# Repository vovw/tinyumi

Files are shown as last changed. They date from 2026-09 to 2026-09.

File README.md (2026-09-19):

# tinyumi :3

A hand-worn, 3D-printable UMI-style gripper for experiments with the I2RT YAM
linear gripper. Forked from [Yosub Shin’s YAM-UMI](https://github.com/YosubShin/yam-umi).

**tinyumi adds Quest controller supports, printed rail stops, a RealSense D405
mount, rigid prototype fingertips, and two-plate Bambu print projects.** The
original rack-and-pinion jaws, finger holders and YAM interface remain the basis
of the build.

These additions are **fit prototypes**. CAD and mesh checks are recorded, but
physical fit, strength, full hand/cable clearance and tracking performance are
not yet established. End-to-end data collection is not implemented here. The
D405 has a new camera pose; it does not inherit the original fisheye calibration
or the original camera-to-robot matching claim.

## Print and assemble

1. Choose a [full print project](bambu/full_rebuild/README.md):
   - [D405 version](bambu/full_rebuild/tinyumi_full_rebuild_D405_A1_PETG.3mf).
   - [Original fisheye version](bambu/full_rebuild/tinyumi_full_rebuild_A1_PETG.3mf).
2. Print **one** suitable [left or right Quest support](pos-tracking/quest_mount/handumi_v1/README.md)
   separately if using a controller. It is not included in either full project.
3. Follow the [assembly guide](docs/assembly.md) and [fastener table](docs/fasteners.md).
   Check the actual tip threads before buying or fitting tip screws.
4. Verify free jaw travel, end-stop retention and camera/hand clearance, then
   calibrate the chosen camera and pose source.

The full projects target Bambu A1, 0.4 mm nozzle and PETG. Plate 1 holds the
mechanism with four alternative pinions (install one); plate 2 holds two rigid
prototype tips. Original YAM tips can be used instead of the printed prototypes.
Settings are starting points; inspect supports and slice in Bambu Studio.

## What changed

| Addition | Files and details |
| --- | --- |
| Quest controller support | [Left/right HandUMI-derived supports and revised base](pos-tracking/quest_mount/handumi_v1/README.md) |
| Rail retention | [Four end stops and combined Quest/stop base](hardware/rail_stops/README.md) |
| D405 camera option | [One-piece mount, fit gauge and camera screw limits](hardware/realsense_d405/README.md) |
| Printable fingertips | [I2RT-derived rigid prototypes and print manifests](bambu/full_rebuild/README.md) |
| Assembly documentation | [Build order](docs/assembly.md), [screws and inserts](docs/fasteners.md), [change history](CHANGELOG.md) |

The [original BOM](bom/README.md) lists the baseline rails, bearings, straps and
shop supplies. Add hardware from the fastener table for the chosen options;
upstream prices are historical, not a current tinyumi cost estimate.

## Sources and rebuilding

Original CAD is in `hardware/STEP/` and `hardware/STL/`. Each new hardware folder
includes its generator and validation report. See [rebuilding](docs/rebuilding.md)
for commands and limitations. Legacy CAD and illustration filenames are retained
where they identify an upstream part or are consumed by generators.

The [original design notes](DESIGN.md) preserve the fisheye rationale and upstream
measurements. The [marker-based tracker documentation](pos-tracking/README.md)
remains available; its measurements do not validate the Quest alternative.
The earlier [Quest concept](pos-tracking/quest_mount/README.md) is superseded by
the HandUMI-derived supports.

## License and attribution

Original YAM-UMI design by **Yosub Shin**, under the retained [MIT license](LICENSE).
HandUMI-derived supports are Apache-2.0; I2RT reference meshes and derived tips
include their MIT attribution. See [THIRD_PARTY_NOTICES.md](THIRD_PARTY_NOTICES.md)
and the bundled source licenses. tinyumi is not affiliated with or endorsed by
I2RT, HandUMI, or the original UMI authors.

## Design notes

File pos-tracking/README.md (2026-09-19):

# Position tracking

An alternative [HandUMI controller support adapted for tinyumi](quest_mount/handumi_v1/README.md)
includes left/right CAD, a revised plate and an assembly preview. This is a fit
prototype: real controller fit, hand clearance and tracking need physical checks.

**This is an optional add-on.** The default way to recover wrist pose with
tinyumi is camera SLAM from the wrist fisheye, the same approach the original UMI
used — it needs nothing from this directory and keeps collection portable.

What is here is a **dodecahedral ArUco marker ball** on a stalk, observed by an
external forward-facing camera, for setups that can accommodate a fixed camera.
It measures sub-millimetre on settled holds (numbers below), at the cost of
confining collection to that camera's view. Markers use the **`DICT_4X4_50`**
dictionary.

<p align="center">
  The assembled tinyumi gripper with the dodecahedral ArUco marker ball mounted on its wrist stalk
</p>
<p align="center"><em>The assembled gripper with the dodecahedral tracker on its
stalk, held clear of the hand and of the fisheye camera's view.</em></p>

## Parts

| Part | Size (mm) | Notes |
|---|---|---|
| `dodeca_marker_ball_v2` | 51.05 across | Regular dodecahedron; carries the 15 mm markers |
| `stalk_rod_80mm` | 8 × 8 × 80 | Rod holding the ball clear of the hand |
| `wrist_stalk_adapter_v3` | 44 × 14 × 29 | Mounts the stalk to the wrist |
| `wrist_stalk_arc_adapter` | 44 × 14 × 49.8 | Arc-mount variant of the adapter |
| `arc_extender` | 43.5 × 41.5 × 57 | Extends the arc mount |
| `retainer_radial_tab` | 60.3 × 14 × 75.6 | Retains the ball on the stalk |

A dodecahedron is used so that at least one face is well-conditioned for pose
estimation from any viewing direction, which removes the orientation blind spots
a single planar marker has.

## Markers

`marker_sheet_ball_15mm_FIXED.pdf` — **15 mm markers on 19.5 mm tiles**, applied
to the twelve faces of the ball.

> **Print at 100% scale.** In the print dialog, choose *Actual size* and disable
> *Fit to page*, *Shrink oversized pages*, and any scaling. A sheet printed at
> 97% produces pose estimates that look plausible and are wrong by 3% in range —
> a failure that will not announce itself.

After printing, measure a marker with calipers against 15 mm before cutting
anything out. This takes ten seconds and is the only check that catches a
mis-scaled print.

Apply markers with double-sided tape across the **entire** face, not just the
edges, so they cannot curl or lift. A marker that bows near an edge biases the
corner detection that pose estimation depends on.

### Marker placement is not prescribed

There is deliberately **no face-to-ID mapping to follow**. Apply the twelve
markers to the twelve faces in any arrangement, then recover the layout by
running the assembled ball through a solver that estimates each marker's pose in
the ball's body frame from observations across many viewpoints.

This is worth understanding before you build: the ball's geometry is calibrated,
not assumed. It means print-and-stick tolerances are absorbed by the calibration
rather than becoming permanent error, and it means **your ball's mapping will
differ from anyone else's** — the calibration output is specific to the physical
unit you built and has to travel with it.

<!-- TODO: point at the solver. Right now a reader has the hardware and the
     marker sheet but no way to get from "ball with stickers on it" to a usable
     pose stream. Either link the tool you used, name the off-the-shelf
     equivalent, or write down the procedure and the output format. This is the
     single biggest gap for anyone trying to reproduce the tracking. -->

### Measured performance

All figures below were taken with the ball at roughly 94 cm standoff from the
external camera, **on settled holds**.

**Precision**

| Metric | Result |
|---|---|
| Within-hold | 0.46 mm RMS (median), p90 0.68 mm |
| Revisit repeatability | 0.08–0.17 mm SD per axis (lateral 0.12, depth 0.17) |

**Coverage** — the fraction of frames with enough faces visible to solve a bundle
pose. This is where the choice of external camera shows up:

| Camera | ≥1 face | ≥2 faces | ≥3 faces |
|---|---|---|---|
| Sony (4K 30p, H.264) | 100% | 90.8% | 77.5% |
| Arducam B0591 (1080p, focus locked via v4l2) | 79.6% | 68.3% | 59.1% |

The B0591 numbers were measured before any mount or field-of-view tuning for
that camera. The 15 mm faces give it comfortable pixels at this range, so the
gap to the Sony is a field-of-view and mounting difference rather than a
sensor limit — treat 68% as a floor, not a verdict on cheaper webcams.

#### The camera that ended up winning: Arducam B0587 (4K low-light)

After the table above we moved to the **Arducam B0587** (4K STARVIS2 sensor,
~88° FOV, UVC/MJPEG) and it became the workhorse — it is the camera behind
every number in [`dynamic-accuracy.md`](dynamic-accuracy.md):

| Metric | Result |
|---|---|
| ChArUco intrinsics | 0.744 px RMS at 4K |
| Rigid marker-pair RMS (best pairs) | 0.7 mm |
| Detection vs arm speed | flat to 3 m/s — no measured ceiling |
| Per-frame ≥1-face detection, full teleop session | 99.97% |

**Why it works — the motion-blur unlock.** Fiducial tracking during motion
dies by corner smear, not by frame rate: at 25 fps a marker moving 1 m/s
travels 40 mm between frames, but what kills the *decode* is how far it moves
during the *exposure*. The recipe is a very fast shutter on a sensor that can
afford it:

- **Exposure 0.2 ms** (`exposure_time_absolute=2`, manual mode, gain 0,
  sharpness 0). At 0.2 ms, even 3 m/s of motion smears only 0.6 mm —
  sub-pixel at ~1 m standoff — so the corner detector simply never sees
  blur, and the speed ceiling disappears.
- **A low-light sensor makes that exposure usable.** 0.2 ms under ordinary
  indoor lighting starves a typical webcam sensor; the STARVIS2's
  sensitivity yields clean, zero-gain images at that shutter in a bright
  lab. This pairing — fast shutter *enabled by* low-light silicon — is the
  whole trick, and it is worth selecting cameras for explicitly. (In dim,
  ceiling-light-only conditions the same camera certified at 1 ms +
  gain 20 with equivalent tracking quality.)

Hard-won caveats that travel with this camera class:

1. **Control readback lies.** UVC exposure writes are accepted and read
   back correctly *whether or not the imaging pipeline latched them* — and
   on some modules they only latch after streaming has started. Apply the
   settings mid-stream and verify **behaviourally**: wave a hand in front
   of the lens; at 0.2 ms it must be frozen, not smeared. We lost a full
   session to trusting readback before learning this.
2. **Image brightness is not an exposure probe** on HDR/tone-mapping ISPs —
   some modules normalise brightness toward a target regardless of the real
   exposure. Streaks and blur are the probe; brightness is not.
3. **Some modules' `focus_absolute` is accepted but inert** (the B0587
   focuses by physically rotating the barrel only). Verify focus with a
   live sharpness meter, then mechanically lock the barrel with a witness
   mark — and recalibrate intrinsics after *any* barrel movement.
4. **Flickering LED lighting strobes at sub-millisecond shutters.** Room
   light that looks steady to the eye can beat against a 0.2 ms exposure;
   use DC or high-frequency-driven lighting for the capture volume.

#### Locking focus on the external camera

**Lock the external camera's focus before collecting anything.** The Arducam is
an autofocus module, and autofocus is actively harmful here: refocusing changes
the effective focal length, which shifts the pose solution under a camera the
calibration assumes is fixed. The result is drift that looks like tracking noise
and is not.

There is no hardware switch — set it through V4L2 on Linux. Control names differ
across kernel and driver versions, so list them first:

```
v4l2-ctl -d /dev/video0 --list-ctrls
```

Then disable autofocus and pin a focus value, using whichever names appeared
(`focus_automatic_continuous` on newer uvcvideo, `focus_auto` on older):

```
v4l2-ctl -d /dev/video0 --set-ctrl=focus_automatic_continuous=0
v4l2-ctl -d /dev/video0 --set-ctrl=focus_absolute=<value>
```

Pick the value by focusing on the ball at your working standoff, reading back
`focus_absolute`, then setting it explicitly. These controls reset when the device
is replugged, so reapply them at the start of every session — or with a udev rule
— and re-run the camera calibration if the focus value ever changes.

#### What these numbers do and do not support

1. **Settled holds only** — *resolved 2026-09*: dynamic tracking has since
   been certified on the real arm at full manipulation speed; see
   [`dynamic-accuracy.md`](dynamic-accuracy.md). The 0.46 mm figure remains
   the settled-hold precision, consistent with the 0.7 mm rigid-pair RMS
   measured there.
2. **Relative, not absolute** — *resolved 2026-09*: the 14% scale / 9°
   direction discrepancies were extrinsics error, fixed by a proper
   robot-world hand-eye calibration; absolute robot-frame pose now agrees
   with forward kinematics to 7.7 mm median / 22.7 mm p95, with the
   hand-eye residual (4.8 mm) as the floor. Details and method in
   [`dynamic-accuracy.md`](dynamic-accuracy.md).

<!-- TODO: publish the calibration procedure itself — how the bundle solve is run
     and what it outputs — so someone else can reproduce these numbers rather than
     just read them. -->

## Aperture markers

Gripper aperture is read from ArUco markers on the gripper tips, seen by the
wrist fisheye camera.

`markers/tip_markers_9mm_ID13_14.pdf` — **9 mm markers, IDs 13 and 14**, one per
tip. The 9 mm size is chosen to stay resolvable in the fisheye view, where the
tips sit well off-axis and the effective resolution is much lower than the
sensor's nominal figure suggests.

The same 100% scale rule and full-face taping apply as for the ball markers
above.

Each marker sits **25 mm from the gripper base** — as far from the fisheye camera
as the tip's flat area allows. The camera looks down at an angle, so distance from
it moves the marker toward the centre of the frame and away from the distorted
edge; the limit is mechanical, not optical, since the tip narrows and eventually
offers no flat patch wide enough to seat a marker. See
[assembly](../docs/assembly.md#4-aperture-markers).

An earlier variant detected aperture from the external forward-facing camera
instead, using 12 mm markers on printed tails that carried them behind the jaws.
That approach and its parts live in a separate repository, since they belong to
the external-camera setup rather than to this one.

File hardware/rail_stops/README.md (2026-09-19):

# Rail end stops

Four small printed stops for the two 100 mm MGN9 rails in tinyumi. Each stop
bolts to an end face of the printed plate and catches the outer shoulder of a
carriage. The top stays below the moving jaw adapter.

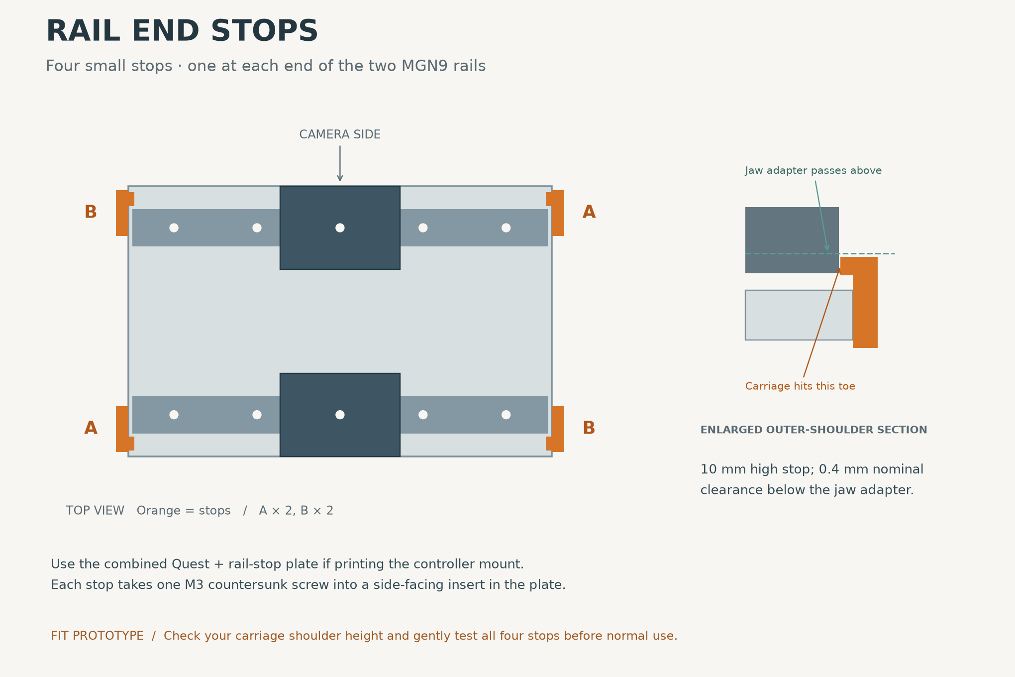
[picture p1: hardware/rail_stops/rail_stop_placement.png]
Placement


## Print these

- **`rail_stops_four_flat.3mf`**: recommended; four separately named objects,
  broad mounting faces flat on the bed, 8 mm gaps and matching A/B diagonals.
  This is a geometry-only 3MF; select your printer and PETG profile in the slicer.
- `rail_stops_four_on_plate.stl`: the same corrected arrangement as one STL.
  This file replaces the earlier upright print layout.
- Individual parts: `rail_stop_A_print_2.stl` and `rail_stop_B_print_2.stl`.
  Print two of each; use A on one diagonal pair of corners, B on the other.
- **`plate_v6_quest_and_rail_stops.stl`**: use this replacement plate for the
  Quest mount plus these stops. It includes both sets of insert holes.
- `plate_v6_with_rail_stops.stl`: alternative plate for the stops alone.

Editable STEP files accompany each part. `build.py` generates the geometry,
placement drawing and checks; `validation.json` records their results.

**The existing plate has no side-facing holes for these stops.** Print the
appropriate revised plate. Both the stock plate and the earlier Quest-only
plate need this revision to accept the stops as drawn. The rails stay standard.

## Hardware and assembly

Per gripper, add four M3 x 5 mm heat-set inserts with nominal 4 mm OD and four
M3 x 8 mm, 90-degree countersunk screws. These are additional to the two screws
and inserts used by the Quest support.

1. Print the stops in PETG, approximately 0.2 mm layers and four walls. The
   individual stop STLs and four-part layout now sit broad-face down on Z=0,
   4.5 mm high, with vertical screw holes and countersinks facing the bed.
   See `rail_stops_print_layout.png`. Print settings are a starting
   point, not experimentally verified settings.
2. Fit the four inserts into the **narrow end faces** of the new plate, with the
   insert axes parallel to the rails. Nominal centres are x=±51, y=±24.5,
   z=3 mm in the plate frame; bores are 4 mm diameter and 5.4 mm deep. Check your
   insert's actual knurl diameter before fitting. There is only 1 mm nominal
   wall above and below each bore, so avoid overheating the pocket.
3. Bolt one stop at each corner using the A/B arrangement shown above. The small
   raised toe points inward along the rail and sits on the outside shoulder of
   its carriage. Seat screws without crushing or twisting the printed stop.
4. Gently slide each carriage toward each stop. It must contact the toe while
   remaining fully on the rail. Check that the carriage cannot lift, bypass or
   rotate the stop. Then sweep the gripper through its intended opening range.

Keep a temporary restraint at the rail ends until all four stops have passed
that check. These are stops for hand-operated travel, not crash bumpers.

## Geometry and checks

The stop face is at x=±49.5 mm, 0.5 mm inboard of the nominal 100 mm rail ends.
The toe spans z=7.8–10.0 mm; the adapter CAD starts at z=10.4 mm, leaving 0.4 mm
nominal vertical clearance. All stop material lies outside |y|=20.5 mm, clear
of the reference finger-holder envelope by about 0.48 mm. These are small
nominal clearances and require checking against the printed assembly.

Nominal MGN9C dimensions from the [HIWIN catalogue](https://www.hiwin.com/wp-content/uploads/HIWIN-Linear-Guideway-Catalog.pdf)
are rail width 9 mm, rail height 6.5 mm, carriage width 20 mm, carriage length
28.9 mm and carriage underside height 2 mm above the mounting surface. With
the rail mounted on the plate's z=6 mm face, the outer carriage shoulder begins
at z=8 mm and meets the toe. Clone carriages can differ: **verify that your
carriage actually has a shoulder in the z=7.8–10.0 mm band.**

For that nominal block, the stop gives approximately ±35.05 mm of carriage-centre
travel, a total 70.1 mm. This is carriage travel, not gripper aperture. The
existing assembly GLB uses a simplified carriage envelope; this contact check
uses the catalogue dimensions rather than treating that envelope as supplier CAD.

Checks run: valid single CAD solids, watertight stop and plate STLs, no stop/plate
or stop/rail intersection, nominal carriage contact before the rail end, and
adapter/finger-holder clearance. Actual clone dimensions, physical full-stroke
operation, screw fit, impact resistance and retention remain untested.

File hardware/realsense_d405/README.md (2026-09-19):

# RealSense D405 replacement mount

A one-piece PETG bracket replacing the original fisheye mount on one tinyumi.
It fits the existing camera insert pair on the underside of plate_v6, including
the combined Quest + rail-stop plate. No new holes in the gripper base are required.

- `d405_mount_print.stl`: oriented printable part; supports required.
- `d405_mount_assembly.step` / `.stl`: part in the base's assembly coordinates.
- `d405_rear_fit_gauge.stl`: small 5 mm-thick test piece for the D405 rear screw pair.
- `d405_on_base.glb` / `d405_mount_preview.png`: schematic camera envelope on the base.
- `D405_ENVELOPE_NOT_FOR_PRINT.step`: nominal body envelope, not supplier CAD.
- Updated full print project: `../../bambu/full_rebuild/tinyumi_full_rebuild_D405_A1_PETG.3mf`.

## Screws and installation

1. Check the rear-hole gauge against the camera before printing the long bracket.
2. Attach the camera to the bracket with **two M3x8 socket-head screws** through
   the 5 mm pad: nominal penetration is 3 mm. The camera's maximum M3 insertion
   is **4 mm**. Measure the printed pad and actual screw protrusion; do not force
   a screw that bottoms out. No heat-set inserts are needed at this joint.
3. Attach the foot under the base's camera-side end with **two M3x8, 90-degree
   countersunk screws**, entering the existing base inserts. The foot is 5 mm
   thick at the screw axis, giving about 3 mm engagement. Base inserts retain
   their existing specification; supplier-specific hole resizing is not applied.
4. Both lenses face the tips. The stereo baseline runs along jaw travel.
   Rear access and both cable sides are open; check the actual Micro-B plug and
   cable bend before tightening. Tie the cable to the arm with slack at the plug.
5. Sweep the jaws and try the hand straps before use. Check camera view across
   the complete aperture range.

## Geometry and print setup

The base pair is at X=±20.285398 mm, Y=29 mm in the existing plate frame.
The camera rear pair is horizontal, 20 mm apart, on a 42x16x5 mm back pad.
Most of the camera back and all side faces remain exposed.

Camera rear centre: (0,100,0) mm; view direction (0,-0.707107,0.707107).
The 45-degree angle aims toward the nominal fingertip region near (0,0,100).
This is a chosen design pose, not a preserved fisheye extrinsic or measured
optical centre. The 42x42x23 mm body envelope does not include the side protrusion
or a cable plug. Neither side is enclosed by the bracket.

Print STL bounds: 54x86x30.657 mm. Full project uses A1/0.4 mm, PETG, 0.2 mm
layers, four walls, 30% gyroid, normal snug supports. Remove supports from screw
holes and both mounting faces before assembly. Physical fit/strength untested.

CAD checks: single valid solid, watertight mesh, zero nominal base/body overlap,
and a 33.9 mm Y gap from camera envelope to a conservative moving-jaw band.
Hand/strap/cable geometry is not included. These are geometric checks, not load
or full-motion certification.

## Camera integration

This is a mechanical change only. The D405 is a close-range stereo camera, not
the original fisheye. Capture integration, camera calibration, marker visibility,
and camera-to-gripper extrinsics need checking with the D405 before collecting
usable data. Existing fisheye calibration must not be reused.

## Dimensional source

RealSense D400 Series Datasheet, October 2025, Figure 10-13, printed page 146:
https://realsenseai.com/wp-content/uploads/2025/09/Intel-RealSense-D400-Series-Datasheet-October-2025.pdf
Rear M3 pair: 20 mm pitch; maximum insertion 4 mm; body 42x42x23 mm.
Original bracket design in this folder; camera envelope is schematic.

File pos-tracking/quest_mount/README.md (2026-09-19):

# Quest Touch Plus mount — concept v0

**Superseded:** use the [actual HandUMI support adaptation](handumi_v1/README.md).
The tall-cradle files below are retained as an earlier design study.

Design study for tinyumi with Quest 3 / 3S and Touch Plus controllers. This is a
prototype concept, not a fit-verified production part. Controller contact shape,
tracking visibility, fastener access and full hand/jaw clearance need physical
verification. No Quest tracking integration has been installed or measured here.

## Deliverables

- `quest_mount_concept.png`: annotated CAD concept view.
- `quest_mount_CONCEPT.step`: editable solid for fitting in CAD.
- `quest_mount_CONCEPT.stl`: prototype mesh; not a release-ready print.
- `build_concept.py`: parametric source and reproducible rendering/export.
- `concept_validation.json`: geometric checks and explicitly unverified items.
- `controller_ENVELOPE_NOT_FOR_FIT.stl`: simplified visual placeholder only.

The initial flange pitch is 40.57 mm, taken from the circular edge centers at
x = ±20.285, y = 29 mm in `hardware/STEP/plate_v6.step`. These are 4 mm diameter
features; the concept uses M3 clearance holes for an insert-based attachment.
This is an interface candidate, not proof of available mounting real estate:
the camera already uses this region. Resolve the installed camera fastener
stack, access, actual thread and full surrounding clearances before fitting.
The exported part is in its own local frame, not a verified assembly transform.

Nominal concept dimensions: 56 x 24 x 6 mm flange, 62 mm controller-axis offset,
4 mm saddle wall, 48 mm saddle height and two 10 mm retention bands. The
38 x 34 mm inner ellipse is a provisional contact envelope, not a measured
Touch Plus cross-section. It must be refitted before tightening onto a controller.
The displayed bands are illustrative purchased straps; the controller envelope
and bands are excluded from the printable mount STL.

For a first fit coupon, section just the saddle in CAD and check it against the
controller before printing the bridge. PETG is a reasonable prototype material;
use multiple walls and orient the bridge to avoid a weak layer-peel load path.
Print settings and strength are not validated. Measure the final fastener stack
before choosing screw lengths, and add a loose controller safety tether.

## Recommendation

Prototype Quest as an alternative pose source. It can remove the external pose
camera, marker-ball calibration and ball stalk from portable collection. Keep
the YAM wrist camera and aperture markers: a controller measures its own pose,
not the opening of the mechanical jaws. The wrist camera USB cable remains.

At the time of this concept study, the repo reported 0.46 mm RMS within settled holds, not moving TCP
accuracy, and unresolved 14% scale / 9 degree direction discrepancies against
robot FK. The subsequently merged [upstream dynamic-accuracy report](../dynamic-accuracy.md)
updates those baseline limitations; it does not validate this Quest concept.
Quest is not a demonstrated accuracy upgrade. Its benefit is likely
collection convenience; dynamic accuracy, occlusion, drift and reacquisition
need an apples-to-apples comparison. The tracker solver itself was not found in
this checkout, so this comparison uses its hardware and published measurements.

## Mechanical layout

Borrow HandUMI's controller-over-the-hand arrangement, while keeping this
project's YAM camera-to-jaw geometry. Use a rigid load path:

    stationary gripper plate -> short braced bridge -> controller cradle

Do not use the moving finger holders or a skin-mounted wrist strap as the pose
reference. Do not put a controller on the existing 80 mm, 8 x 8 mm marker stalk
without a separate stiffness/load assessment. A wrist strap can be a loose
safety tether, but must not change the controller-to-gripper transform.

The proposed concept has a two-screw mounting flange, a short boxed/gusseted
bridge and an open cradle. A hard locating surface and two separated retention
bands resist sliding and rotation. Thin replaceable pads protect the controller;
soft padding must not become the structural reference. Final pads and locating
surfaces must match a measured controller section. The opening is deliberately
parametric rather than claiming a scan-derived Touch Plus fit.

Keep the controller face, upper perimeter, lower tracking region, buttons and
trigger clear. The controller bottom remains open. Verify IR visibility with
the real controller and headset, including both hands crossing, palm-down
grasps, reaching into shelves and looking away. Mounting the controller on a
gripper differs from its normal held-in-hand use and must be validated as such.

Use the shortest bridge that clears the actual hand and wrist-camera image.
Start with a fixed mount; change its geometry between trials rather than using
an unlocked ball joint. Every change to controller seating or mount geometry
requires a new controller-to-TCP calibration. Left and right controller contact
surfaces should be fitted separately rather than assuming perfect mirroring.

## Pose integration

[HandUMI Quest App](https://github.com/murobotics-ai/handumi-quest-app) already
streams controller and headset telemetry. Its
[protocol](https://github.com/murobotics-ai/handumi-quest-app/blob/main/protocol.md)
documents newline-delimited JSON over TCP port 65432, tracked/valid flags,
runtime timestamps and UDP clock synchronization on port 42000. Its presence
does not by itself make the tinyumi recording pipeline complete.

There is also a local `vr-teleop-kit` project with a Quest WebXR pose transport.
Its clutching, gain scaling and IK outputs are for teleoperation. For physical
demonstration recording, take raw metric poses before those modifications.
Record the exact pose reference used (grip versus aim, runtime convention),
source time, reception time, tracking state and coordinate-frame convention.

With T_A_B mapping coordinates from B into A:

    T_world_tcp(t) = T_world_controller(t) * T_controller_tcp

Calibrate both translation and rotation of T_controller_tcp with a rigid
fixture and multiple orientations. Pivot calibration alone finds an offset;
it does not determine the complete orientation alignment. If deployment needs
the robot base frame, additionally calibrate T_robot_world. Verify handedness,
quaternion order, metres and axis conversion with known translations/rotations.
Do not multiply by the HMD pose again if the app already sends world poses.

Synchronize Quest source time with wrist video and aperture timestamps. TCP
arrival time is not acquisition time. Record/reject stale and invalid poses;
never silently carry a frozen pose through a tracking outage. Split or reject
episodes after recentering/relocalization discontinuities until the world frame
is re-established. Quest still uses internal tracking/SLAM; it removes the need
to implement an offline wrist-camera pose solver, not every calibration step.

## Before choosing it over the ball

1. Fit the cradle to the actual Touch Plus controller. Confirm no button preload,
   bottom obstruction or controller slip, and full aperture/hand/camera clearance.
2. Attach both trackers temporarily to the same rigid body, keeping both visible.
   Measure their fixed extrinsic and time offset; compare at the same TCP.
3. Record static holds, repeated fixture returns, measured straight motions,
   fast wrist rotations, occlusions and ten-minute trajectories. Include removal
   and reinsertion of the controller to measure mount repeatability.
4. Compare valid-frame fraction, outage duration, recovery jumps, lag, relative
   trajectory agreement and start/end drift. Use an independent measured fixture
   or calibrated reference for absolute error: disagreement alone cannot tell
   which tracker is right, especially with the existing unresolved FK comparison.
5. Choose acceptance limits from the intended manipulation task before comparing.
   Keep the ball as a debug/reference option until Quest passes those limits.

Mount stiffness matters: 1 degree of angular motion over a 150 mm lever arm
produces about 2.6 mm of apparent TCP displacement. Those are illustrative
values, not measured dimensions or errors for this build.

## Sources and scope

- [HandUMI hardware](https://github.com/murobotics-ai/handumi-hw): controller
  supports and wrist-mounted VR tracking. Local reference inspected at ef0c784.
  Arrangement inspiration only; no upstream CAD is copied into this concept.
- [HandUMI software](https://github.com/murobotics-ai/handumi-sw): Quest support
  and physical controller-to-TCP calibration metadata.
- [Current tracker](../README.md) and [tinyumi](../../README.md): existing
  mechanism, marker geometry, measured settled-hold statistics and limitations.

Upstream pages inspected 2026-09-12. This work adds a design study alongside the
existing tracker; it does not claim the Quest replacement has been validated.

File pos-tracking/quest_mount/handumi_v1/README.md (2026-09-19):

# HandUMI controller support adapted for tinyumi

This replaces the earlier tall-cradle concept. The controller rings come from
HandUMI's actual left and right STEP files. Their mounting forks are trimmed
and replaced with short angled tabs. One support attaches with two screws.

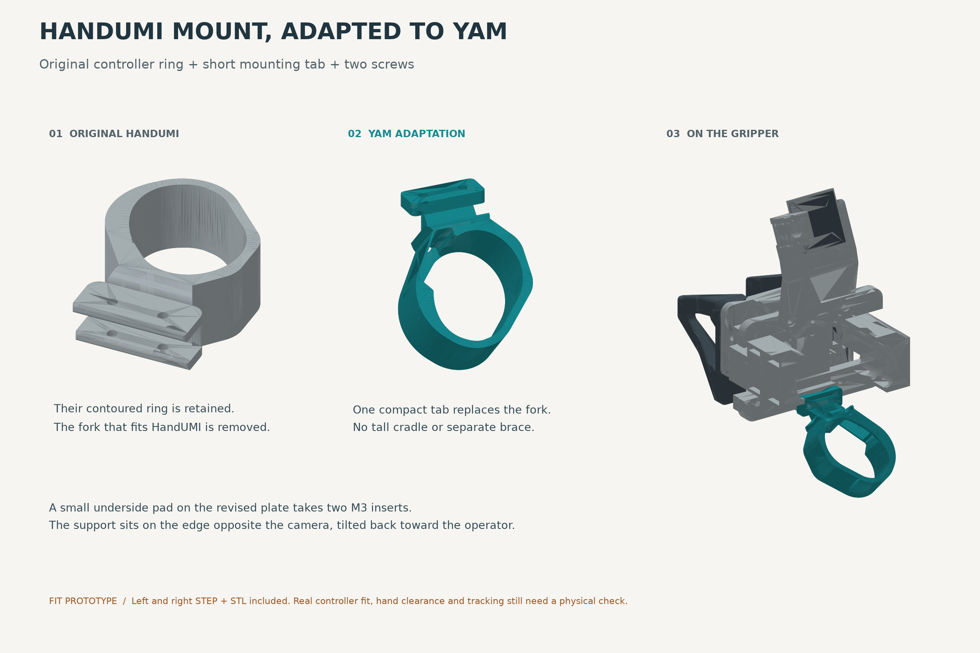
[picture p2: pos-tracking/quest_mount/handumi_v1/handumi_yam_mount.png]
Adaptation


## Files

- `handumi_yam_right_support.step` / `.stl`: adapted right support.
- `handumi_yam_left_support.step` / `.stl`: adapted left support.
- `plate_v6_handumi_mount.step` / `.stl`: revised stationary plate, used with
  either support. **This support needs the revised plate; it does not bolt onto
  an unmodified plate_v6.**
  If your rails lack end stops, use the
  [combined Quest + rail-stop plate](../../../hardware/rail_stops/README.md)
  instead; it also accepts the four printed rail stops.
- `yam_with_handumi_mount.glb`: assembly preview, in metres. Other assembly
  components come from the existing illustration and include simplified parts.
- `build.py`: repeatable CAD modification, export, rendering and checks.
- `validation.json`: geometric results and remaining physical checks.
- `source/`: pinned, unmodified upstream supports and Apache-2.0 licence.

## What changed

The original contoured rings and their existing retention features are retained.
The HandUMI-specific fork attachment is replaced by a small two-hole tab and
short neck. The ring is tilted 45 degrees back toward the operator, on the edge
opposite the camera. There is no tall cradle, additional cage or separate brace.
The left and right sources are distinct parts, not assumed mirror copies.

The revised plate adds a 30 x 12 x 4 mm pad on its underside, centred at
(0, -26.5) mm in the original plate frame. Two insert bores are centred at
(±8, -28) mm: 16 mm pitch, nominal 4 mm bore diameter and 5.4 mm depth from the
pad underside. Material above z=2 mm is unchanged, retaining the original rail,
pinion and camera geometry. Existing rail or camera screws are not repurposed.

The support tab is 5 mm thick with 3.4 mm clearance holes and 6.4 mm countersink
mouths. Start with two M3 x 5 mm heat-set inserts, OD 4 mm, and two M3 x 10 mm
90-degree countersunk screws. Verify the actual insert fit and screw engagement
before assembly; insert knurl specifications vary. The tab meets the underside
pad at z=-4 mm. The source CAD units and all exported STEP/STL units are mm.

## Fit prototype, not a tested release

The support and plate are valid single solids with watertight meshes. The build
checks support/plate interference and conservative bounding-box clearance against
the existing assembly. Moving-part X bounds are expanded over the plate width
to check lateral jaw travel; this is a geometry screening check, not a dynamic
simulation or a measured assembly fit.

**The upstream files do not establish a physically verified Touch Plus fit for
your particular controllers.** Their original controller contact geometry is
preserved rather than replaced with the guessed ellipse from the first concept.
Try the appropriate ring on your Quest 3 / 3S controller before printing the
replacement plate. Do not force it on or sand away a locating surface without
checking tracking and repeatability again.

Check the real controller body, buttons, tracking surfaces, hand, wrist, straps
and USB cable in the mounted position. Those are not modelled in the assembly
clearance check. In particular, the controller body can occupy space beyond the
printed ring. Use a loose safety tether during trials and confirm the controller
cannot slide or rotate in the ring. Tracking accuracy and print strength have
not been tested. Keep the original camera and aperture-marker setup.

For prototype printing, PETG matches the existing build. Orient the support in
the slicer with the neck load path in mind and inspect required supports; the
STLs retain assembly coordinates, not a prescribed print orientation. Check
insert fit on a small coupon first.

## Provenance and licence

Modified from [murobotics-ai/handumi-hw](https://github.com/murobotics-ai/handumi-hw)
at commit `fc7462ad1ed58c0c8538f6c7dbb732211d088ca8`:

- `hardware/STEP/right_handumi/right_controller_support.step`
- `hardware/STEP/left_handumi/left_controller_support.step`

The upstream parts and derived supports are distributed under Apache-2.0; see
[source/LICENSE](source/LICENSE). Modifications made 2026-09-12: removed the
original fork mounting ends, transformed ring placement, added YAM mounting
tabs, and created the associated plate interface. Original source STEP files
are retained unmodified, with SHA-256 hashes in `validation.json`.

The plate derives from this repository's `hardware/STEP/plate_v6.step`. Assembly
illustrations also use the repository's existing I2RT-derived tip meshes; see
the root `THIRD_PARTY_NOTICES.md` for their provenance.

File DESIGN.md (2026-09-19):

# Original YAM-UMI design notes

Upstream design rationale and measurements through `9d202bc`. These describe the original camera and marker-tracker builds, not validation of tinyumi’s Quest, D405, rail-stop or printed-tip additions. See the [tinyumi README](README.md) for the current build.

# YAM-UMI

An open-source, hand-worn [UMI](https://umi-gripper.github.io/)-style data
collection device for the **[I2RT YAM](https://i2rt.com/products/yam-6-dof-arm)
arm's linear gripper**.

YAM-UMI is deliberately built for one arm.
It mirrors the YAM linear gripper's jaw geometry, reuses the YAM wrist camera
mount, and reproduces the gripper's own rail-and-pinion mechanism, so **the
camera pose relative to the gripper tips, and the way those tips move, are the
same during data collection as on the deployed robot**. Aperture is recovered
from ArUco fiducials rather than a servo encoder, so there is no motor to
backdrive and no loaded plastic linkage to fail.

<p align="center">
  The YAM arm's linear gripper beside the YAM-UMI handheld device, showing matched jaw geometry and the same wrist camera mount
</p>
<p align="center"><em>Left: the YAM arm's gripper. Right: YAM-UMI. Same jaw geometry,
same camera mount, same tips — so the wrist camera sees the same thing in both.</em></p>

<p align="center">
  Operator performing a pick-and-place with the YAM-UMI gripper, dodecahedral tracker visible above the wrist
</p>
<p align="center"><em>Pick-and-place demonstration, with the dodecahedral wrist tracker
attached. Full quality: <a href="media/demo-pick-place.mp4">demo-pick-place.mp4</a>.</em></p>

> **Status: hardware released, pipeline in progress.** The mechanical design is
> printed and assembled, and the optional wrist tracker is characterised for
> settled holds (0.46 mm RMS). End-to-end data collection and policy training with
> this device have not been run yet, and the parity claims below are by
> construction rather than measured — see
> [Status and limitations](#status-and-limitations).

## Why another UMI variant

The point of a UMI-style rig is to collect demonstrations without a robot in the
loop, then train a policy that consumes wrist-camera images. That only works if
what the camera sees at collection time resembles what it sees at deployment
time.

That principle is UMI's own, not this project's. The
[UMI paper](https://arxiv.org/abs/2402.10329) states it directly — *"When
deploying UMI on a robot, we place GoPro cameras with the same location with
respect to the same 3D-printed fingers as on the hand-held gripper"* — and reports
wrist-camera video that is "almost indistinguishable" between demonstration and
deployment.

What differs between designs is the **direction** in which the match is made. UMI
adapts the robot to the interface: mount UMI's fingers and a GoPro on any arm with
a parallel jaw stroke over 85 mm, and the match follows. YAM-UMI adapts the
interface to the robot: the arm keeps its stock gripper tips and stock camera
mount, and the handheld device changes to match. That direction suits a fleet
already standardized on one arm, or a deployment configuration you would rather
not modify — at the cost of fitting nothing else.

This design began as an attempt to use
[HandUMI](https://github.com/murobotics-ai/handumi-hw) on a YAM. HandUMI is one
of the few open hand-worn UMI designs whose linkage keeps the two jaws
**synchronized**, moving together the way a parallel gripper does rather than
independently following the operator's two fingers. For anyone targeting a linear
gripper that property is the hard part, and it made HandUMI the natural starting
point here. Two things kept it from working on a YAM.

### 1. The camera extrinsic could not be matched

HandUMI takes a third position: rather than adapting either side, it keeps one
shared body across arms and swaps only the gripper tips, leaving the rest to
software retargeting. That is what lets a single rig serve an AgileX Piper, an ARX
X5, a Trossen WidowX and others — but it means the wrist camera sits where the
shared body allows, and its mount does not readily adjust to reproduce the YAM
camera's angle relative to the gripper tips. The resulting viewpoint shift is a
domain gap the policy has to absorb.

YAM-UMI instead reuses the YAM gripper's own fisheye camera mount on a body that
reproduces the YAM jaw geometry, so the camera-to-tip transform is matched by
construction rather than corrected in software. Because the device also accepts
the **actual gripper tips that ship with the YAM arm**, the jaws occlude the same
part of the frame, the aperture-to-pixel mapping is the same, and the contact
patch on the object is the same.

The cost is generality: this rig targets the YAM linear gripper and nothing else.
That is a deliberate trade, not an oversight.

### 2. The servo and the lever linkage

HandUMI measures aperture with a Feetech servo encoder, which gives a clean
per-frame width signal. The operator pays for it by backdriving the servo through
its gear train on every pinch, adding friction to the one motion the device
exists to record faithfully.

The linkage was the more immediate problem. In hand, its printed lever parts
popped out of the mechanism under normal use — the load path runs through
printed plastic links, and that is where it failed.

YAM-UMI carries the motion on two MGN9 linear rails instead, with a single pinion
between two racks — one rack per jaw — to keep the jaws synchronized.

**This is the mechanism the YAM gripper itself uses.** Two MGN9 rails, two racks,
and a pinion is not an arbitrary alternative to the crank linkage; it is what is
inside the robot's own linear gripper. So the parity here is not only optical and
geometric but *kinematic*: the jaws travel the way the robot's jaws travel, the
aperture is symmetric about the same centerline, and the relationship between the
operator's pinch and the resulting width is the one the robot can actually
execute. There is no mechanism-level retargeting between collection and
deployment, because there is no mechanism difference to retarget.

Aperture is read from ArUco markers, the approach the original UMI used.
Consequences:

- **No backdrive friction.** The pinch is governed by the rails and the
  rack-and-pinion coupling only.
- **No servo, controller, or power supply** in the bill of materials, and no
  cable routing for them.
- **No loaded lever linkage.** The printed parts are brackets and mounts, not
  structural links carrying the pinch load.

<p align="center">
  View from the gripper tip side: a central pinion meshing with a rack on each jaw, keeping the two jaws synchronized
</p>
<p align="center"><em>Viewed from the tip side: one pinion between two racks, one rack
per jaw, riding two MGN9 rails — the same arrangement as inside the YAM arm's own
linear gripper. A single-handed pinch drives both jaws symmetrically, with no
servo in the loop and no linkage carrying the load.</em></p>

## What it records

| Signal | Source |
|---|---|
| Wrist pose, SE(3) | Camera SLAM from the wrist fisheye — the original UMI approach, and the default here. Optionally, a dodecahedral ArUco marker ball observed by an external camera |
| Gripper aperture | 9 mm ArUco markers on the gripper tips, seen by the wrist fisheye camera |
| Wrist-view video | Fisheye USB camera on the YAM camera mount |

SLAM is the default because it keeps collection portable, which is the whole
point of a UMI-style rig. Nothing in this repository is required for it — the
wrist camera and mount are all it needs.

### Optional: dodecahedral wrist tracker

If your setup can accommodate a fixed external camera, this repository also
includes a dodecahedral marker ball and the mounts that attach it to the gripper.
It buys precision at the cost of confining collection to the camera's view.

Measured with the ball at roughly 94 cm standoff, **on settled holds**:

| Metric | Result |
|---|---|
| Within-hold precision | 0.46 mm RMS (median), p90 0.68 mm |
| Revisit repeatability | 0.08–0.17 mm SD per axis (lateral 0.12, depth 0.17) |

Coverage — the fraction of frames with enough faces visible to solve a bundle
pose — depends strongly on the external camera:

| Camera | ≥1 face | ≥2 faces | ≥3 faces |
|---|---|---|---|
| Sony (4K 30p, H.264) | 100% | 90.8% | 77.5% |
| Arducam B0591 (1080p, focus locked via v4l2) | 79.6% | 68.3% | 59.1% |

**Update (2026-09):** both of the original caveats — settled-holds-only, and
absolute pose unresolved — have since been resolved by measuring this same
ball design on the real YAM arm against its joint encoders. During full-speed
teleoperated manipulation (30 episodes, ~23k frames), fused-ball pose agrees
with the robot's forward kinematics to **7.7 mm median / 22.7 mm p95 / 1.7°**
at a tool point 13 cm from the ball, with pose solved in 98.5% of frames;
the error budget is dominated by the hand-eye calibration (4.8 mm residual),
not the camera. The earlier 14%/9° discrepancies were extrinsics error, fixed
by a proper `calibrateRobotWorldHandEye` solve harvested from ordinary
episodes. Full numbers, method, and known failure modes:
[`pos-tracking/dynamic-accuracy.md`](pos-tracking/dynamic-accuracy.md).

The Arducam coverage was measured before any mount or field-of-view tuning for that
camera, so it is a floor rather than a verdict on cheaper webcams.

See [`pos-tracking/README.md`](pos-tracking/README.md) for the build and
calibration procedure.

A VR-controller mount is not provided but would be straightforward to add —
contributions welcome.

## Parts

### Gripper body — [`hardware/`](hardware/)

Printed parts are provided as STEP and STL. The STEP files are the source of
truth; the STLs were tessellated from them at 0.05 mm chordal tolerance and are
watertight, so re-export from STEP if you want a different resolution.

| Part | Size (mm) | Role |
|---|---|---|
| `plate_v6` | 102 × 65 × 10.4 | Main plate; carries both linear rails, the camera arm, and the pinion axle |
| `adapter_v10` | 50 × 25.9 × 10.6 | Carriage-to-jaw adapter; presents the YAM gripper tip interface |
| `pinion_z18_deep_v0`–`v3` | ⌀20.0–19.7 × 10.6 | Module 1, z=18 spur pinion coupling the two jaw racks for symmetric motion, as in the YAM gripper. Four fit variants — see [Printing](#printing) |
| `handle_v13` | 32 × 17 × 55 | Operator handle |
| `L_bracket_v3` | — | Camera arm bracket |
| `YAM_linear_gripper_fisheye_camera_mount` | — | Fisheye camera mount, matching the YAM wrist camera pose |

<!-- TODO: confirm the Role column. The pinion/rack coupling is confirmed by the
     tip-side photo, but the plate, adapter, handle and bracket roles are still
     inferred from geometry rather than from your notes. -->

**Gripper tips are not printed.** Use the "Linear 4310" tips that ship with the
YAM arm — that is what makes the contact geometry identical to deployment. If you
do not have spares, I2RT sells them as
[Gripper Tips (for Linear-Gear Style Gripper)](https://i2rt.com/products/gripper-tips-for-linear-gear-style-gripper)
($69), though they are frequently out of stock.

### Position tracking — [`pos-tracking/`](pos-tracking/)

See [`pos-tracking/README.md`](pos-tracking/README.md) for marker specifications
and printing instructions.

- `wrist_dodecahedron_marker/` — the dodecahedral marker ball (51 mm across),
  its stalk, wrist adapter, arc adapter, extender, and retainer, plus the 15 mm
  marker sheet.
- `markers/` — the 9 mm tip-marker sheet (IDs 13, 14) used for aperture sensing
  from the wrist fisheye camera.

Marker placement on the ball is not prescribed: stick the twelve markers on in
any arrangement and recover the face-to-ID mapping by calibration. That absorbs
print-and-stick tolerances instead of baking them in as permanent error, but it
also means each ball's calibration is specific to the unit it was measured on.

## Build

- [Bill of materials](bom/README.md) — ~$79 per gripper in parts, plus shop supplies (filament, fastener kits, tape) if you are starting from nothing.
- [Assembly](docs/assembly.md) — build order and fastener placement.

### Printing

Everything was printed in **PETG** on a Bambu Lab X2D with the stock PETG profile
and *Support for PLA/PETG* enabled. No part needed tuning beyond support
settings. PLA should work too — nothing here runs warm and it is an indoor,
hand-held device — PETG is simply what these were printed in.

**The pinion comes in four variants.** `pinion_z18_deep_v0`–`v3` are the same
18-tooth, module-1 pinion at descending outside diameter — 20.0, 19.9, 19.8 and
19.7 mm — a 0.1 mm clearance ladder against the racks. **Print all four on one
plate and pick the one that runs smoothest** in your assembly. Printer, filament
and insert alignment all shift the effective fit, so the right variant is
empirical rather than predictable; `v3` was the best fit in the reference build,
which is why the rest of the docs name it.

## Status and limitations

- **No end-to-end result yet.** The device has not been used to collect a dataset
  and train a policy. The camera-extrinsic parity claim is by construction and
  has not been validated against recorded imagery.
- **Wrist tracker: settled-hold precision 0.46 mm RMS at ~94 cm; dynamic
  tracking and absolute robot-frame pose are now certified** (7.7 mm median
  agreement with the arm's forward kinematics across full-speed
  manipulation) — see
  [`pos-tracking/dynamic-accuracy.md`](pos-tracking/dynamic-accuracy.md).
- **The tracker's calibration procedure is not published**, so the numbers above
  can be read but not yet reproduced.
- **Aperture accuracy is unmeasured.** A comparison of fiducial-derived width
  against the YAM encoder, or against calipers over a swept aperture, would be
  the most valuable single addition to this repo.
- **Fiducial occlusion** is an inherent failure mode; there is no fallback width
  estimate when markers are lost.
- **Single-arm scope.** No support for other grippers is planned.

## Related work

- **[UMI](https://umi-gripper.github.io/)** (Chi et al.,
  [arXiv:2402.10329](https://arxiv.org/abs/2402.10329)) — the original handheld
  gripper, the source of both the fiducial-based aperture sensing this design
  returns to and the principle of minimizing the observation embodiment gap.
  UMI achieves that match by mounting its own fingers and camera on the robot;
  YAM-UMI reverses the direction.
- **[HandUMI](https://github.com/murobotics-ai/handumi-hw)** (Murobotics) — the
  direct starting point for this work, and one of the few open hand-worn UMI
  designs with a synchronized parallel-jaw mechanism. YAM-UMI takes the
  glove-style form factor and the hook-and-loop finger retention from it, and
  diverges on camera placement, jaw mechanism, and aperture sensing for the
  reasons above. If you want a robot-agnostic rig rather than a YAM-specific one,
  or a direct encoder reading of aperture, HandUMI is the better fit. No HandUMI
  CAD is used here.
- **[Generalist](https://generalistai.com/)** — the wearable data-collection
  approach HandUMI credits as its own motivation.

### The robot this targets

- **[YAM 6-DOF arm](https://i2rt.com/products/yam-6-dof-arm)** (I2RT Robotics) —
  the arm YAM-UMI is built for. 6 DOF, 2 kg payload, 95 mm gripper throw.
- **[YAM documentation](https://doc.i2rt.com/products/yam)** — specifications and
  setup for the arm and its linear gripper.
- **[`i2rt-robotics/i2rt`](https://github.com/i2rt-robotics/i2rt)** — the Python
  client library, URDF, and robot meshes. The meshes there are what this design's
  gripper geometry and camera mount are dimensioned from; see
  [THIRD_PARTY_NOTICES.md](THIRD_PARTY_NOTICES.md).

## License and attribution

This project is released under the [MIT License](LICENSE).

Geometry in this repository is dimensioned from mesh files published by I2RT
Robotics under the MIT License. See
[THIRD_PARTY_NOTICES.md](THIRD_PARTY_NOTICES.md) for the full attribution.

**This project is not affiliated with, endorsed by, or sponsored by I2RT
Robotics.** "YAM" is used only to identify the robot arm this hardware is
designed for.

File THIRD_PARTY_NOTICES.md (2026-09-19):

# Third-Party Notices

This project incorporates or derives from third-party material. Each item below
lists what was used and the license it was used under.

## YAM-UMI — original gripper design

tinyumi is a derivative of [YosubShin/yam-umi](https://github.com/YosubShin/yam-umi),
started from commit `2862fe2` and merged through `9d202bc`. The original MIT license and Yosub Shin copyright
notice are retained in [LICENSE](LICENSE). See [CHANGELOG.md](CHANGELOG.md)
for this fork’s additions. Historical design notes and measurements are
preserved in [DESIGN.md](DESIGN.md).

## I2RT — reference meshes and prototype fingertips

`hardware/reference/i2rt_linear_4310/` includes pinned upstream tip meshes,
model XML and MIT license. [source.json](hardware/reference/i2rt_linear_4310/source.json)
records the source commit, paths and hashes. The print prototypes in
`bambu/full_rebuild/tip_*_prototype.stl` trim those meshes to remove the stock
rack; assembly illustrations also derive from these meshes. This is an
additional use beyond the original camera interface described below.

## HandUMI — optional controller supports

`pos-tracking/quest_mount/handumi_v1/` contains original and modified controller
support CAD from [murobotics-ai/handumi-hw](https://github.com/murobotics-ai/handumi-hw),
commit `fc7462ad1ed58c0c8538f6c7dbb732211d088ca8`, under Apache-2.0.
The upstream licence is included in that folder's `source/LICENSE`.
The modified supports retain the controller rings and replace the mounting ends
to attach to tinyumi. See the folder README for source paths and modification
details. These optional supports are an exception to the original-work statement
about `pos-tracking/` below.

## I2RT Robotics — YAM robot models and CAD

This design is dimensioned from three sets of files published by I2RT Robotics
for YAM owners:

- the **YAM URDFs**,
- the **camera mount CAD** for the linear-gear gripper, and
- the **gripper cable retainer**.

Together these are what make the gripper geometry and the wrist camera pose match
the deployed robot.

**Scope of what is derived.** I2RT's plate CAD is supplied as a single merged
mesh, so it provides overall form but no separable components. In the original YAM-UMI release, the gripper mechanism was drawn
from scratch — `plate_v6`, `adapter_v10`, `L_bracket_v3`, `handle_v13`, the pinion
variants, and all of `pos-tracking/` are original work, dimensioned either
independently or by measuring the physical robot. The derived content is the
mounting geometry needed to make the camera pose and jaw interface match, not the
mechanism.

**Source.** These were taken from the CAD folder I2RT distributes to customers,
linked from the [YAM product page](https://i2rt.com/products/yam-6-dof-arm) and
hosted on
[Google Drive](https://drive.google.com/drive/folders/17en5gl898ILuapsgUwBkjy4y5SOWQhB2).
That folder carries no stated licence or terms of use.

**Licence status.** I2RT publishes the same designs, in mesh form, in their
open-source [`i2rt-robotics/i2rt`](https://github.com/i2rt-robotics/i2rt)
repository under the MIT Licence — including
`i2rt/robot_models/arm/yam/v1/` (URDFs and meshes),
`i2rt/robot_models/gripper/linear_4310/assets/d405/camera_bracket_for_D405_linear_4310_.stl`
and `.../Cable_holder.stl`. That MIT grant covers the files in that repository. It
is strong evidence that I2RT intends these designs to be openly used, but it is
not itself a licence for the separately distributed CAD folder, which is where the
geometry used here came from.

The MIT Licence text as published in that repository:

```
MIT License

Copyright (c) I2RT Robotics

Permission is hereby granted, free of charge, to any person obtaining a copy
of this software and associated documentation files (the "Software"), to deal
in the Software without restriction, including without limitation the rights
to use, copy, modify, merge, publish, distribute, sublicense, and/or sell
copies of the Software, and to permit persons to whom the Software is
furnished to do so, subject to the following conditions:

The above copyright notice and this permission notice shall be included in all
copies or substantial portions of the Software.

THE SOFTWARE IS PROVIDED "AS IS", WITHOUT WARRANTY OF ANY KIND, EXPRESS OR
IMPLIED, INCLUDING BUT NOT LIMITED TO THE WARRANTIES OF MERCHANTABILITY,
FITNESS FOR A PARTICULAR PURPOSE AND NONINFRINGEMENT. IN NO EVENT SHALL THE
AUTHORS OR COPYRIGHT HOLDERS BE LIABLE FOR ANY CLAIM, DAMAGES OR OTHER
LIABILITY, WHETHER IN AN ACTION OF CONTRACT, TORT OR OTHERWISE, ARISING FROM,
OUT OF OR IN CONNECTION WITH THE SOFTWARE OR THE USE OR OTHER DEALINGS IN THE
SOFTWARE.
```

I2RT Robotics has not reviewed or endorsed this project. See the non-affiliation
notice in the [README](README.md#license-and-attribution).

## HandUMI (Murobotics)

The original YAM-UMI gripper mechanism did not use HandUMI CAD. The optional
controller supports added in this fork do, as documented above. HandUMI was
the direct starting point for the original work
and is credited as prior art. The design ideas adopted here are the hand-worn,
glove-style form factor, retaining the operator's fingers with hook-and-loop
straps, and keeping the two jaws mechanically synchronized — implemented
independently with a rack-and-pinion on linear rails rather than HandUMI's crank
linkage. HandUMI is licensed under Apache License 2.0.

## Universal Manipulation Interface (UMI)

No CAD from UMI is used here. UMI (Chi et al.) is the origin of the overall
approach, including fiducial-based gripper-aperture sensing, which this design
returns to. See <https://umi-gripper.github.io/>.

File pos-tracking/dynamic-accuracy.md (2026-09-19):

# Dynamic tracking accuracy — dodecahedral ball vs robot ground truth

*Added 2026-09-15. These measurements were made with the same dodecahedral
marker ball and detection stack as this repository, mounted on the real
YAM arm's gripper (not the handheld device), because the robot's joint
encoders provide an independent ground truth that a handheld rig cannot.
They supersede the two standing caveats in the earlier characterisation:
tracking is now certified during dynamic manipulation (not just settled
holds), and absolute pose in the robot frame is resolved.*

## Setup

- Dodeca ball: 11 visible ArUco faces (DICT_4X4_50, ids 0–10), ~12 mm
  face markers, as in [`wrist_dodecahedron_marker/`](wrist_dodecahedron_marker).
- External camera: Arducam B0587 (4K STARVIS2, 88° FOV), fixed scene mount,
  manual exposure 0.2 ms (motion frozen at any arm speed), ChArUco
  intrinsics 0.744 px RMS.
- Detection: OpenCV ArUco with `CORNER_REFINE_APRILTAG` and
  `errorCorrectionRate = 1.0`. The full 1-bit correction is safe with
  DICT_4X4_50: codes sit ≥4 bits apart, so a 1-bit-corrected read cannot
  swap ids; measured cost was 3 spurious *unknown*-id detections per 400
  frames (ignorable), measured gain ~32% recovery of marginal decodes.
- Pose: all visible faces fused into a single PnP solve against the ball's
  bundle model, warm-started frame to frame, 5 px reprojection gate.
- Ground truth: robot forward kinematics from joint encoders, linked to
  the camera frame by a hand-eye calibration (below).

## Absolute pose in the robot frame (the previously unresolved part)

The earlier "median 14% scale and 9° direction discrepancies" were
extrinsics error, as suspected — resolved by a proper hand-eye
calibration: `cv2.calibrateRobotWorldHandEye` over ~600 (camera-frame
ball pose, robot FK pose) pairs harvested from ordinary teleoperation
episodes. This solves both unknowns at once — where the camera sits in
the robot base frame and where the ball sits on the gripper flange:

| Calibration | Reconstruction residual (median) |
|---|---|
| Camera #1 (forward) | 4.8 mm / 0.85° |
| Camera #2 (side) | 4.1 mm / 0.93° |

No dedicated calibration capture is needed — any session with diverse
poses works.

## End-to-end dynamic accuracy

Measured over a full teleoperated manipulation session (30 pick-and-place
episodes, ~23,000 frames at 15 fps, normal arm speeds), fiducial pose vs
FK ground truth, evaluated at a tool point ~13 cm from the ball centre
(where errors are largest — rotation error leverages through the offset):

| Slice | Value |
|---|---|
| Frames with solved pose | 98.5% |
| Position error, median | **7.7 mm** |
| Position error, p95 | 22.7 mm |
| Rotation error, median | 1.7° |
| During grasps specifically | 7.2 mm median |

Two readings of that number:

1. **It is a *disagreement* between two systems**, each imperfect: the
   error budget is dominated by the hand-eye residual (~4.8 mm, plus
   ~2 mm from 0.85° leveraged over the 13 cm tool offset), with the
   robot's own encoders/kinematics inside the "ground truth". The
   camera-side contribution is small: the stack's *relative* precision
   is 0.7 mm RMS on rigid marker pairs (and the 0.46 mm settled-hold
   figure elsewhere in this repo remains consistent with that).
2. For imitation-learning pipelines it is exactly the relevant number:
   labels collected in the fiducial frame meet a robot that acts in its
   FK frame, and 7.7 mm median / 23 mm p95 is the boundary the policy
   experiences. In our downstream experiments, policies trained on these
   fiducial labels reached within ~11% (validation loss) of policies
   trained on robot ground truth under matched conditions — and a
   wrist-camera variant matched ground truth outright.

## Failure modes worth designing around

Across sessions, pose loss concentrated in two geometries, neither of
them decode quality:

- **Frame-edge clipping**: the ball is the highest element on the
  gripper, so high transports push it out of a fixed camera's view
  first. Frame your camera with headroom above the workspace.
- **Self-occlusion**: at some wrist orientations the arm hides the ball.
  A second camera with its own hand-eye recovers these stretches (in our
  worst episode, pose coverage went 26% → 92% by fusing a side camera's
  measurements through the two hand-eye transforms).

Detection itself was not the limiting factor: 99.97% of frames decoded
at least one face (the residual being one genuinely corrupt video frame).

## Reproducing

The measurement needs: (1) the ball on a robot with joint encoders,
(2) one recorded session with pose diversity, (3) intrinsics, (4)
`calibrateRobotWorldHandEye` over the paired poses, (5) per-frame
comparison of fused-PnP pose vs FK through the solved transforms.
Residuals of the hand-eye itself (step 4) set the floor of what step 5
can show.

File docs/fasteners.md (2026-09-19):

# tinyumi screws and inserts

Quantities are for one gripper. **Design sizes** come from the new part geometry;
**CAD starting sizes** require checking the real stack. Neither status means a
physical assembly has been validated. Socket/button screw length is measured
under the head; countersunk length includes the head.

| Joint | Qty | Screw | Basis / receiving thread |
| --- | ---: | --- | --- |
| Rail ends to base | 4 | M3 × 6 socket head | CAD starting size; base M3 inserts, check rail seat |
| Printed rail stops to base | 4 | M3 × 8, 90° countersunk | Design size; side-facing base inserts |
| Adapters to carriages | 8 | M3 × 4 socket head | CAD starting size; check metal carriage M3 threads |
| Pinion axle | 1 | M3 × 12 socket head | CAD starting size; base insert, free bearing rotation required |
| L-brackets to adapters | 4 | M3 × 10 socket head | CAD starting size; adapter M3 inserts |
| Finger-holder centre holes | 2 | M3 × 6 socket head | CAD starting size; holder M3 inserts |
| Fingertips to L-brackets, including shared holder joint | 4 | **M4 × 12 trial only** | Unverified suggestion; actual receiving thread and length unresolved |
| D405 to camera bracket | 2 | M3 × 8 socket head | Design size; 5 mm pad gives nominal 3 mm camera entry; maximum 4 mm |
| D405 bracket to base | 2 | M3 × 8, 90° countersunk | Design size; existing underside base inserts |
| Quest support to base | 2 | M3 × 10, 90° countersunk | Design size; revised underside pad inserts |

## Fingertip joint: measure before tightening

The bracket has approximately 4.6 mm clearance holes on a 21 mm pitch. That
suggests M4 clearance; **it does not prove that the tip has M4 threads**. The
M4 × 12 suggestion is a trial length, not a dimension derived from a verified
assembly. Use it only after confirming the receiving thread or nut arrangement.
There are two screws per tip; one position shares the finger-holder connection,
so the two stacks may require different lengths.

Measure the clamped thickness and available thread depth. The screw must clamp
the entire stack with suitable engagement before bottoming. Do not force an M4
screw into an unknown thread or heat-set an M3 insert into these clearance holes.
For purchased tips, follow the tip’s specified hardware. Rigid printed prototypes
retain source mounting pockets, but their receiving hardware remains unverified.

## Heat-set insert locations

Original specification: M3 thread, nominal 4 mm outside diameter, 5 mm length.
Check actual insert knurl diameter and pocket depth; a supplier’s M3 label alone
does not establish fit.

| Location | Qty |
| --- | ---: |
| Base: four rail mounting positions and central axle | 5 |
| Base: camera underside pair | 2 |
| Base: Quest pad pair, if used | 2 |
| Base: rail-stop end-face holes | 4 |
| Adapters: two per adapter | 4 |
| Finger holders: smaller centre mounting pocket, one each | 2 |

This is 19 inserts with camera, Quest support and printed stops. Install while
parts are separate. **No insert goes in the pinion bearing recess, carriage
screw counterbores or larger fingertip clearance holes.** Let inserts cool,
then check engagement without forcing a bottomed screw.

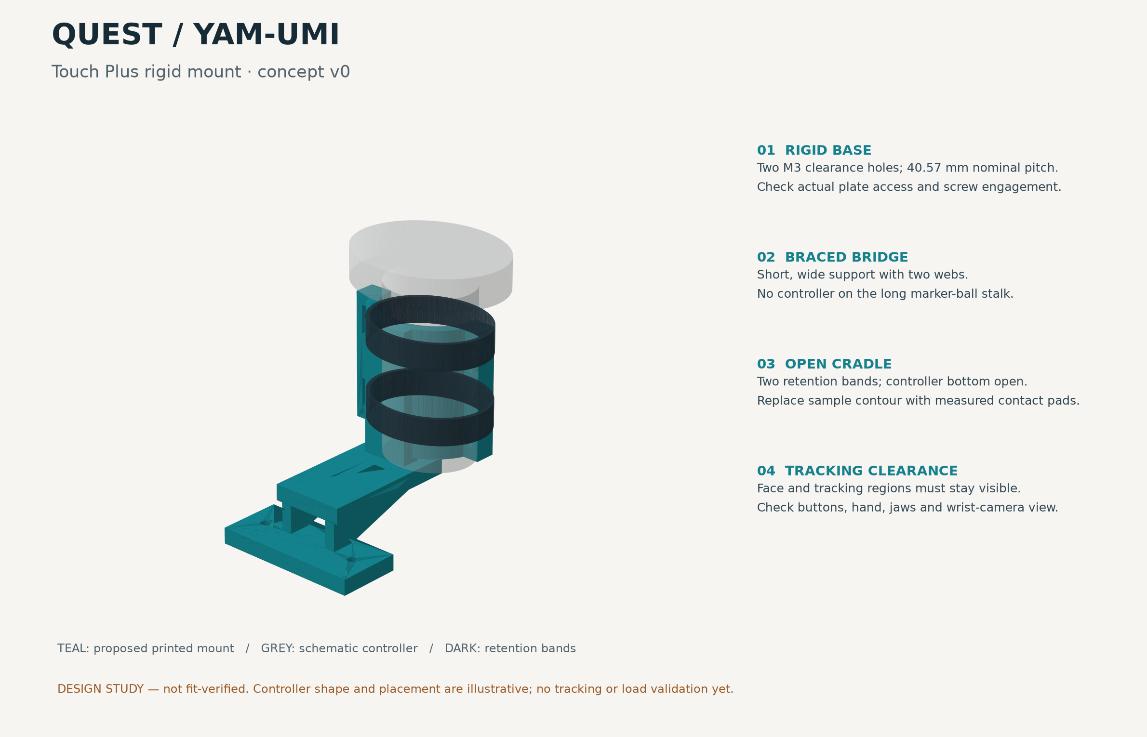
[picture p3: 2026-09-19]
pos-tracking/quest_mount/quest_mount_concept.png

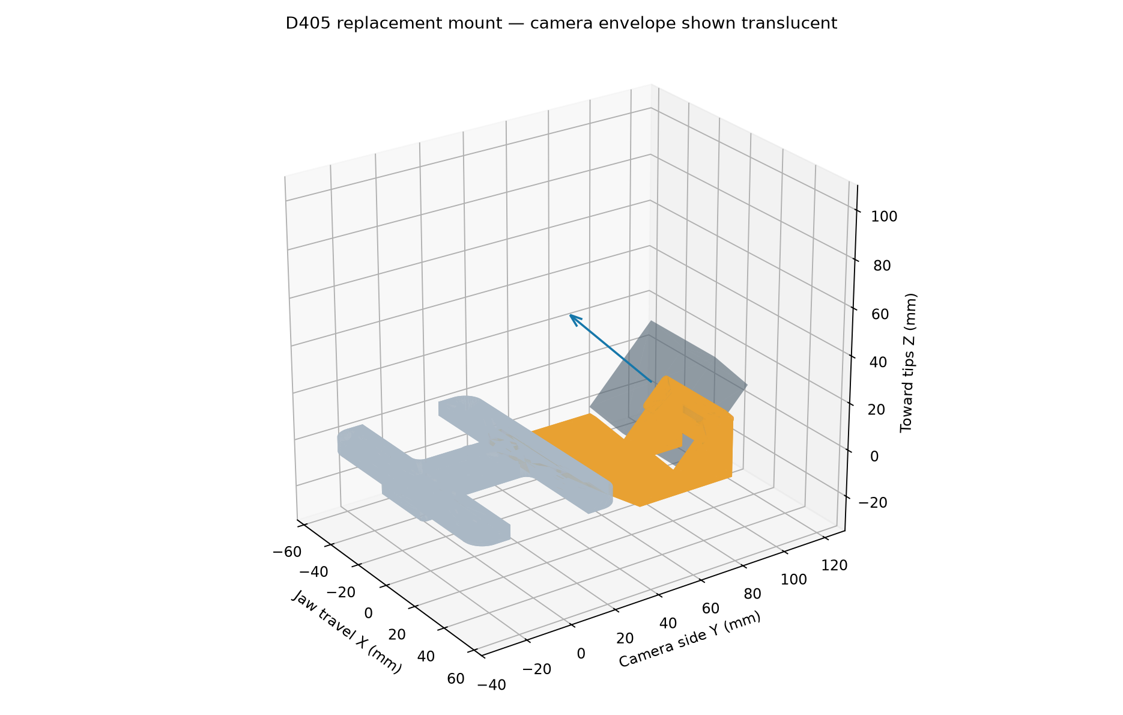
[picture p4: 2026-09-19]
hardware/realsense_d405/d405_mount_preview.png

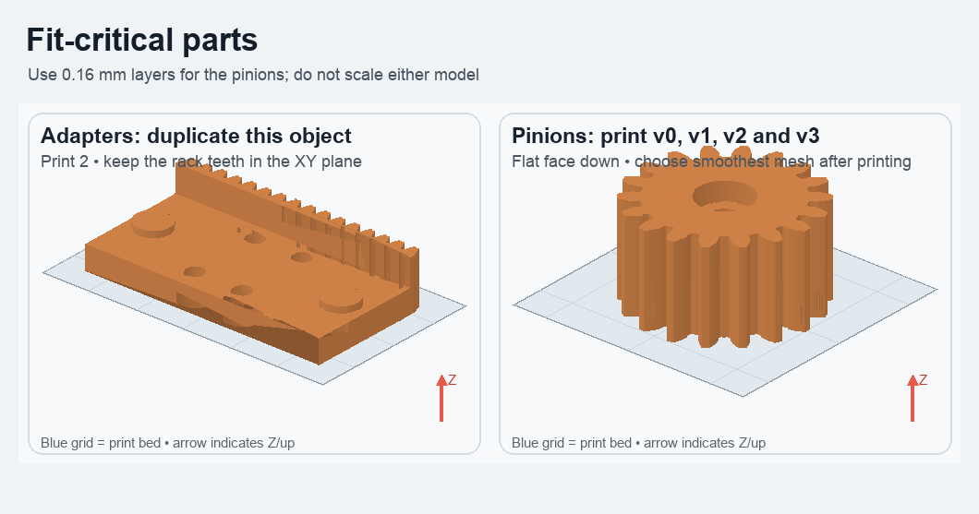
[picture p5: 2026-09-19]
renders/yam_umi_adapter_and_pinion_detail.png

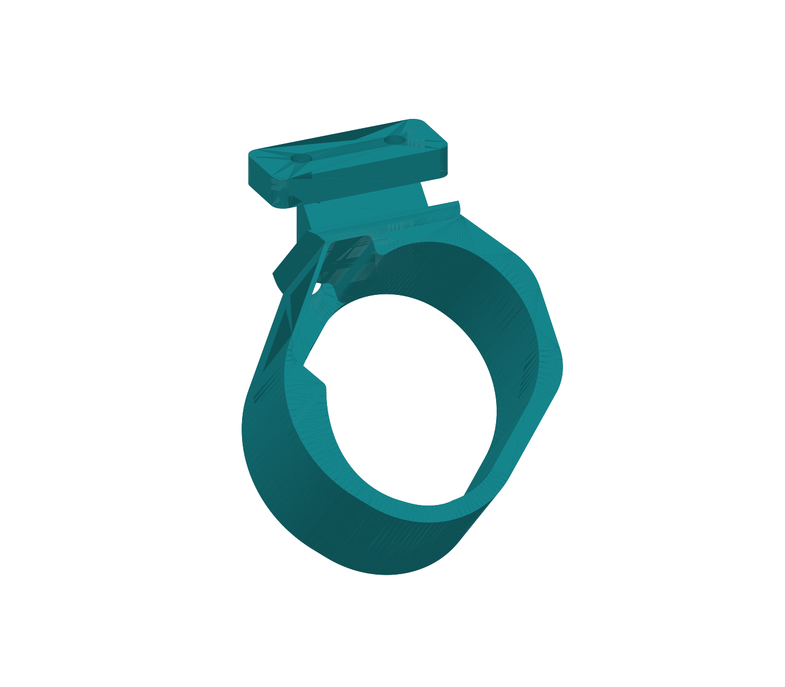
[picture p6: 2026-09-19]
pos-tracking/quest_mount/handumi_v1/support_detail.png

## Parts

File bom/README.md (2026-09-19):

# Bill of Materials

> Baseline upstream BOM. For tinyumi additions and per-joint hardware, see the
> [fastener table](../docs/fasteners.md) and [current build](../README.md). Prices
> below are historical.

Parts needed for **one** tinyumi gripper. Prices are the effective per-unit cost
from the linked listing (pack price ÷ pack quantity) and are reference estimates
only — they move with shipping, region, and availability.

All quantities are confirmed against the assembled prototype.

The list is split in two. **Parts** are what you buy for this project and consume
building it. **[Prerequisites](#prerequisites)** are the workshop supplies and
tools the build draws on — a printer, filament, fastener kits, tape — which anyone
already 3D printing will have on hand. Only Parts are counted in the total, so the
headline figure reflects what this build actually costs you to add.

## Parts

### Motion

One rail and one carriage carry each jaw, so a single gripper needs **two rails
and two carriages** — two sets of the listing below. A bimanual setup needs two
grippers, so four sets.

This mirrors the YAM gripper's own mechanism, which also runs two MGN9 rails with
racks driven by a central pinion. Substituting a different rail size or a single
shared rail would break that correspondence, so treat MGN9 as a fixed choice
rather than a preference.

| Part | Qty | Unit price | Link | Total |
|---|---|---|---|---:|
| MGN9 100 mm linear guide rail + MGN9C carriage block | 2 sets | $9.99 / set | [Amazon](https://www.amazon.com/dp/B0D54LNVKX) | $19.98 |
| Ball bearing, 3 × 6 × 2.5 mm (shielded, MR63ZZ) | 2 (stacked as one pair) | $0.67 / pc ($13.29 / 20) | [Amazon](https://www.amazon.com/uxcell-3mmx6mmx2-5mm-Shielded-Miniature-Bearing/dp/B075CMRGY6) | $1.34 |
| Hook-and-loop straps, 6 in | 2 (one per finger) | $0.19 / pc ($13.99 / 75) | [Walmart](https://www.walmart.com/ip/NavePoint-6-Inch-Hook-and-Loop-Reusable-Strap-Cable-Cord-Wire-Ties-75-Pack-White/180238793) | $0.38 |

> The two bearings stack to give a 5 mm effective width. A single 3 × 6 × 5 mm
> bearing would do the same job in one piece; the pair was used simply because
> that is what was on hand. Either is fine.

> The pinion turns on an **M3 screw** through the stacked bearings, taken from the
> M3 kit in Prerequisites. Leave it slightly loose — see
> [assembly](../docs/assembly.md).

### Optics

| Part | Qty | Unit price | Link | Total |
|---|---|---|---|---:|
| Arducam 1080p fisheye USB camera (IMX291, 160°, UVC, manual-focus lens, w/ mic, 1 m cable) | 1 | $56.99 | [Amazon](https://www.amazon.com/Arducam-Computer-Fisheye-Microphone-Windows/dp/B07ZS75KZR) | $56.99 |

### Gripper tips

| Part | Source |
|---|---|
| YAM gripper tips — "Linear 4310" | **No purchase needed.** Spare tips ship with the YAM follower arm, so if you own a YAM you already have them. Only if yours are lost or damaged, I2RT sells replacements as [Gripper Tips (for Linear-Gear Style Gripper)](https://i2rt.com/products/gripper-tips-for-linear-gear-style-gripper), $69 — nylon with a rubber gripping surface, frequently out of stock. |

### Total

| | |
|---|---:|
| **Per gripper** | **~$79** |
| Bimanual pair (2 grippers) | ~$157 |

The wrist camera is roughly 72% of that. Everything else — rails, carriages,
bearings, straps — comes to about $22.

## Prerequisites

Not counted in the total above. These are shop supplies and tools rather than
parts of the design: if you own a 3D printer you almost certainly have most of
them already, and each covers many builds. Prices are listed so someone starting
from nothing can see the real outlay.

| Item | Used for | Indicative cost |
|---|---|---:|
| 3D printer | Printing the parts; PETG on a Bambu Lab X2D in the reference build | — |
| PETG or PLA filament | ~65 g per gripper (90.6 cm³ solid volume) | ~$1.30 of a $19.99 / kg spool |
| Soldering iron with heat-set insert tip | Installing the threaded inserts; many insert kits bundle one | — |
| [M3 brass heat-set inserts](https://www.amazon.com/Threaded-Inserts-Assortment-Printing-Components/dp/B0DNHLGM8D), M3 × 5 mm × ⌀4 mm | All threads in the printed parts | $12.99 / 100 pc |
| [M3 button-head screw assortment](https://www.amazon.com/dp/B0FQJQNHF5) (840 pc, 8 lengths from 6–30 mm, hex wrench included) | General fastening, plus the pinion shaft screw | see listing |
| [M4 bolt and nut assortment](https://www.amazon.com/Socket-Screw-Assortment-Stainless-Thread/dp/B01F5JI6N8) | General fastening | $16.99 / kit |
| [Scotch double-sided tape](https://www.amazon.com/dp/B0035LXTYU), 1/2 in × 250 in (3-pack) | Mounting the printed ArUco markers | see listing |
| Matte white paper or label stock | Printing the marker sheets | ~$0.10 |
| Calipers | Verifying marker sheets printed at 100% scale | — |
| Small electric screwdriver *(optional)* | Driving the many small screws | — |

Buying all of these fresh runs roughly **$45–60** depending on which kits you
pick — almost all of which carries over to later builds.

A hand driver builds this fine, but a small electric screwdriver was very
convenient — quick bit changes, bits that snap in magnetically, and USB-C
charging. The [HOTO SNAPBLOQ S-A01](https://www.amazon.com/dp/B0DK4XJ9HF) is what
was used here. No affiliation.

Two of the supplies are more particular than they look:

- **Heat-set inserts.** Insert dimensions vary between sellers at the same thread
  size. These parts are drawn for **M3 × 5 mm long × 4 mm OD** — check the seat
  diameter in the STEP files against whatever you buy before printing a full set.
- **Double-sided tape**, specified over glue or edge tape because full-surface
  adhesion keeps the markers flat. A marker fixed only at its edges will curl, and
  a curled ArUco marker degrades pose estimates before it looks visibly wrong.

Fasteners are deliberately given as **assortment kits rather than exact counts**.
The build uses a handful of M3 and M4 screws in a few lengths; pick what fits as
you go rather than working to a parts list.

## Also excluded

- The **external forward-facing camera** used to observe the dodecahedral wrist
  tracker. This is a different camera from the wrist fisheye above, and it is
  needed only for marker-based pose tracking — the SLAM path uses the wrist camera
  alone. Any calibrated camera with a clear view of the workspace works, but
  coverage varies a lot with field of view; see the measured comparison in
  [`pos-tracking/README.md`](../pos-tracking/README.md). The cheaper of the two
  cameras measured there is the
  [Arducam B0591](https://www.amazon.com/dp/B0FX47YSJQ) (1080p30 HDR, 78° diagonal).
  It is an autofocus module, and its focus **must be locked** via V4L2 before use —
  see [`pos-tracking/README.md`](../pos-tracking/README.md).
- The YAM arm itself.

## Comparison

[HandUMI](https://github.com/murobotics-ai/handumi-hw) lists ~$110 per unit. The
figures are not directly comparable: that total amortises pack purchases down to a
per-piece cost — $0.07 of an M3 kit, $2.52 of a filament spool — where the list
above moves those to Prerequisites instead. Counted the same way, tinyumi comes to
roughly **$81** against HandUMI's $110.

The difference is structural rather than incidental. tinyumi drops the Feetech
servo ($13.89), its controller ($10.60) and power supply ($10.00) — about $34 —
and adds two rails and carriages (~$20). It also assumes you already own the YAM
gripper tips, which is reasonable for a rig that only fits a YAM, whereas HandUMI
prints its own tips and targets several arms.

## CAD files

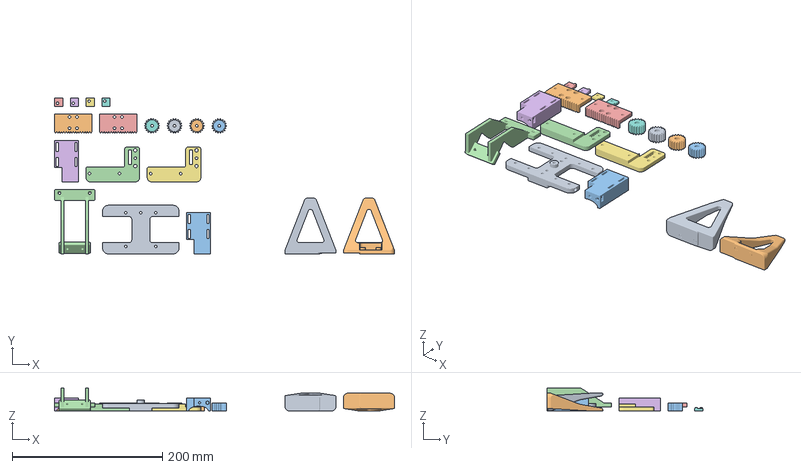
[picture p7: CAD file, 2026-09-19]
bambu/full_rebuild/tinyumi_full_rebuild_D405_A1_PETG.3mf
453.2 x 207.9 x 30.7 mm
Updated base - Quest and stops
Jaw adapter 1
Finger holder 1
L bracket 1
Jaw adapter 2
Finger holder 2
L bracket 2
Pinion v0 - fit test
Pinion v1 - fit test
Pinion v2 - fit test
Pinion v3 - fit test
RealSense D405 camera mount
Rail stop A1
Rail stop A2
Rail stop B1
Rail stop B2
Left fingertip - PROTOTYPE
Right fingertip - PROTOTYPE

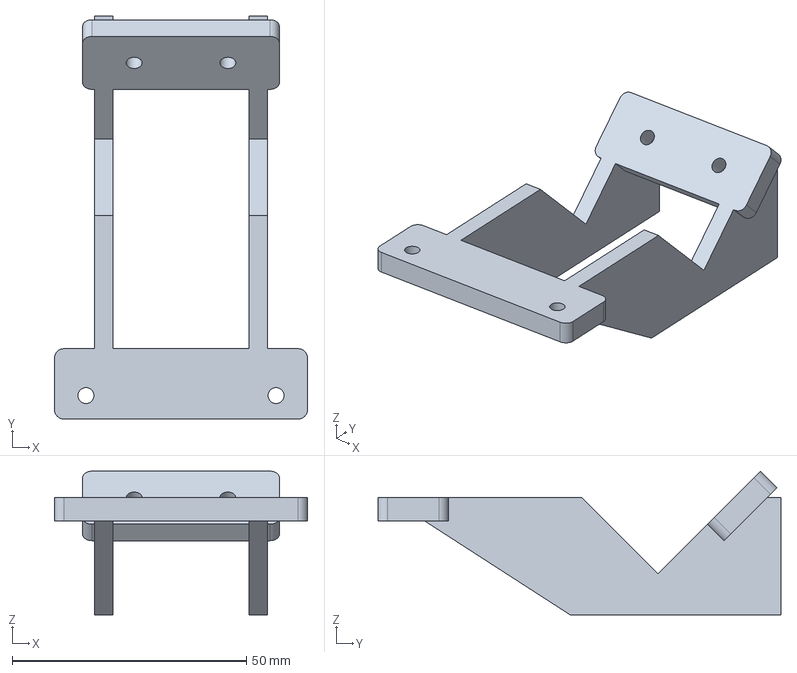
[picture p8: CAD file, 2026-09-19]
hardware/realsense_d405/d405_mount_assembly.step
54.0 x 86.0 x 30.7 mm

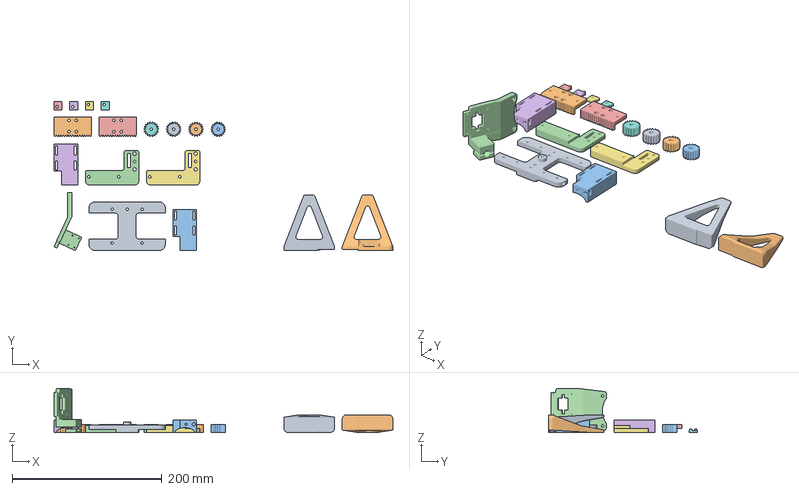
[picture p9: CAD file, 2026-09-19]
bambu/full_rebuild/tinyumi_full_rebuild_A1_PETG.3mf
453.2 x 199.1 x 58.9 mm
Updated base - Quest and stops
Jaw adapter 1
Finger holder 1
L bracket 1
Jaw adapter 2
Finger holder 2
L bracket 2
Pinion v0 - fit test
Pinion v1 - fit test
Pinion v2 - fit test
Pinion v3 - fit test
Fisheye camera mount
Rail stop A1
Rail stop A2
Rail stop B1
Rail stop B2
Left fingertip - PROTOTYPE
Right fingertip - PROTOTYPE

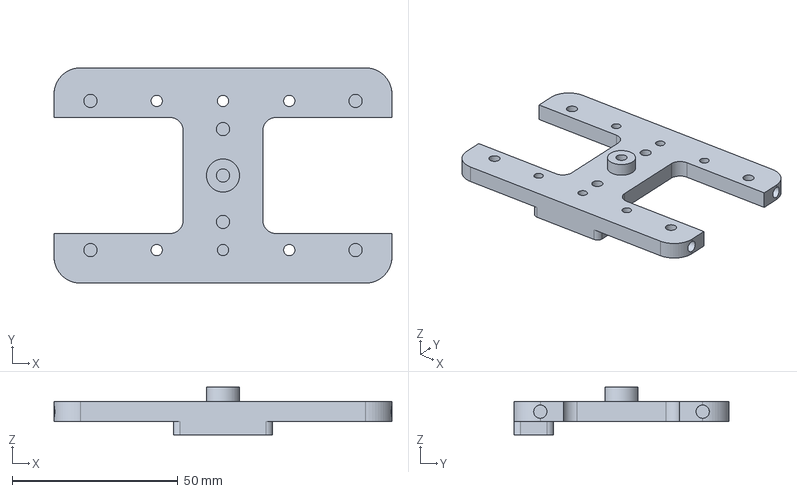
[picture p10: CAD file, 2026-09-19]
hardware/rail_stops/plate_v6_quest_and_rail_stops.step
102.0 x 65.0 x 14.4 mm

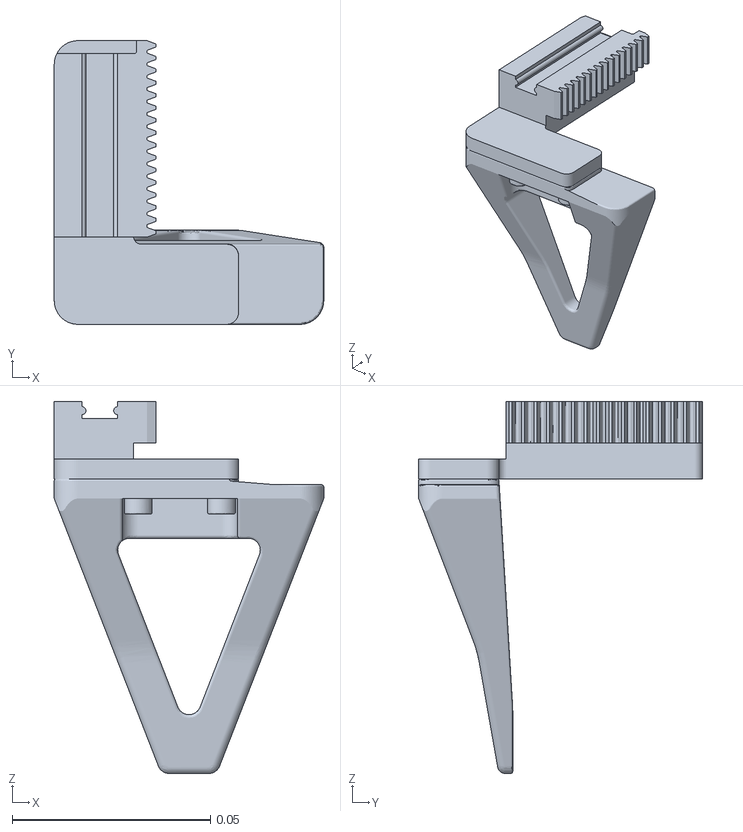
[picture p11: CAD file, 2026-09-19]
hardware/reference/i2rt_linear_4310/tip_left.stl
0.068 x 0.0716 x 0.0938

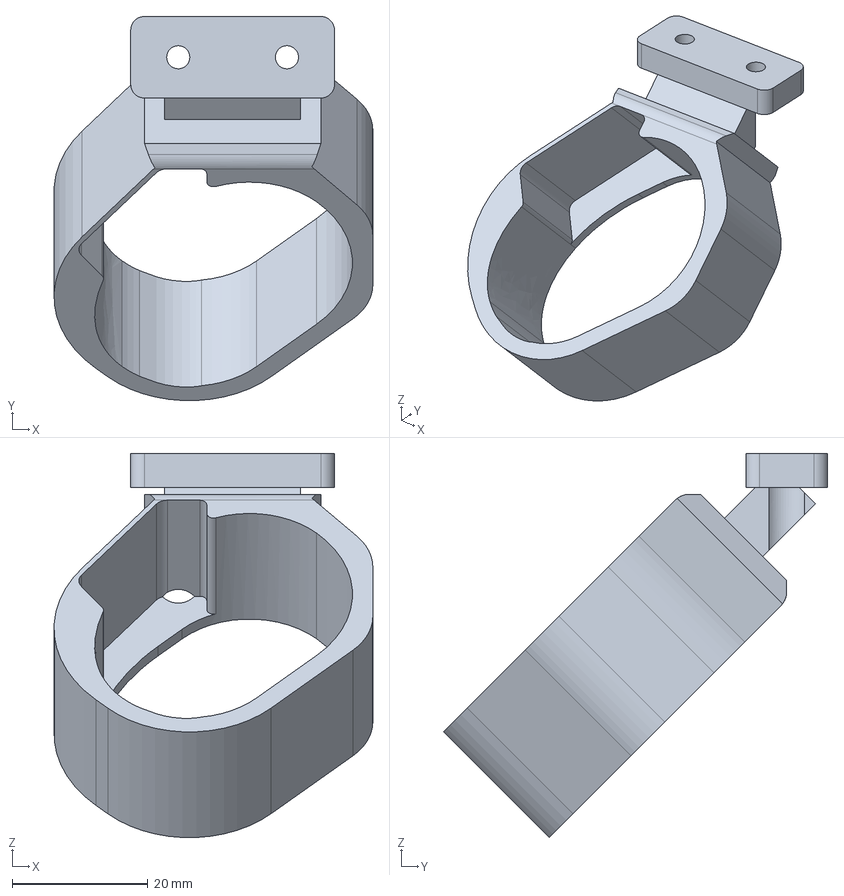
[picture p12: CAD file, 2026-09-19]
pos-tracking/quest_mount/handumi_v1/handumi_yam_right_support.step
46.9 x 56.5 x 56.5 mm

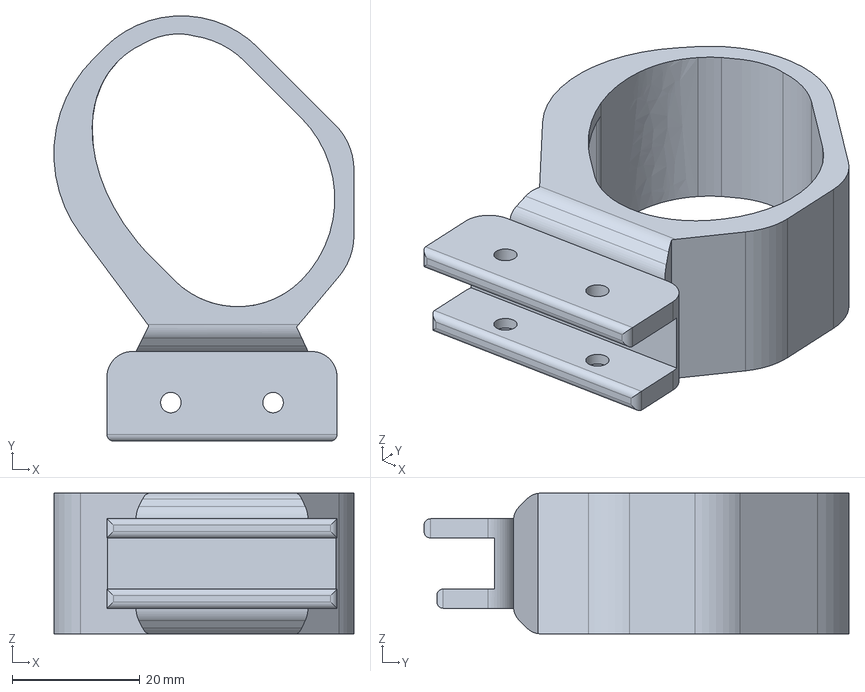
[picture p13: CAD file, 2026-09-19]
pos-tracking/quest_mount/handumi_v1/source/right_controller_support.step
46.9 x 66.5 x 22.0 mm

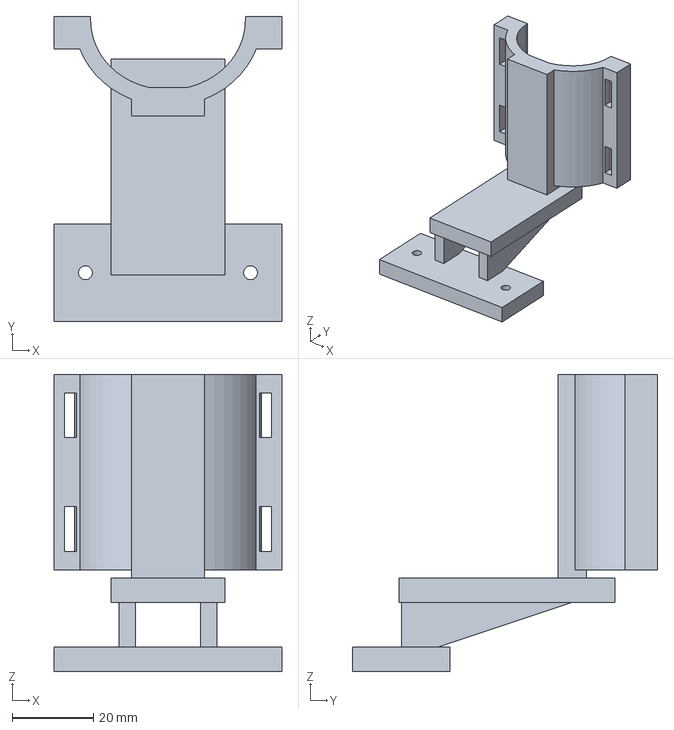
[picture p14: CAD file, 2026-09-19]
pos-tracking/quest_mount/quest_mount_CONCEPT.step
56.0 x 75.0 x 73.0 mm

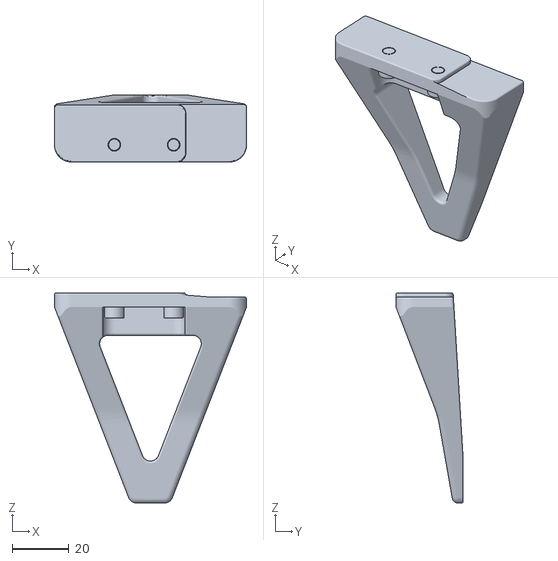
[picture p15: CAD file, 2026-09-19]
bambu/full_rebuild/tip_left_prototype.stl
68.0 x 23.7 x 74.3

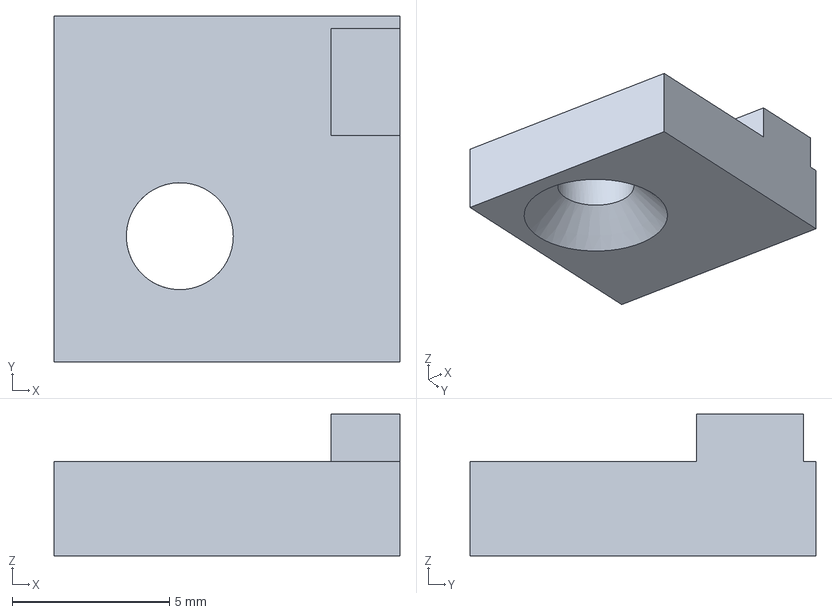
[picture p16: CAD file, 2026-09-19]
hardware/rail_stops/rail_stop_A_print_2.step
11.0 x 11.0 x 4.50 mm

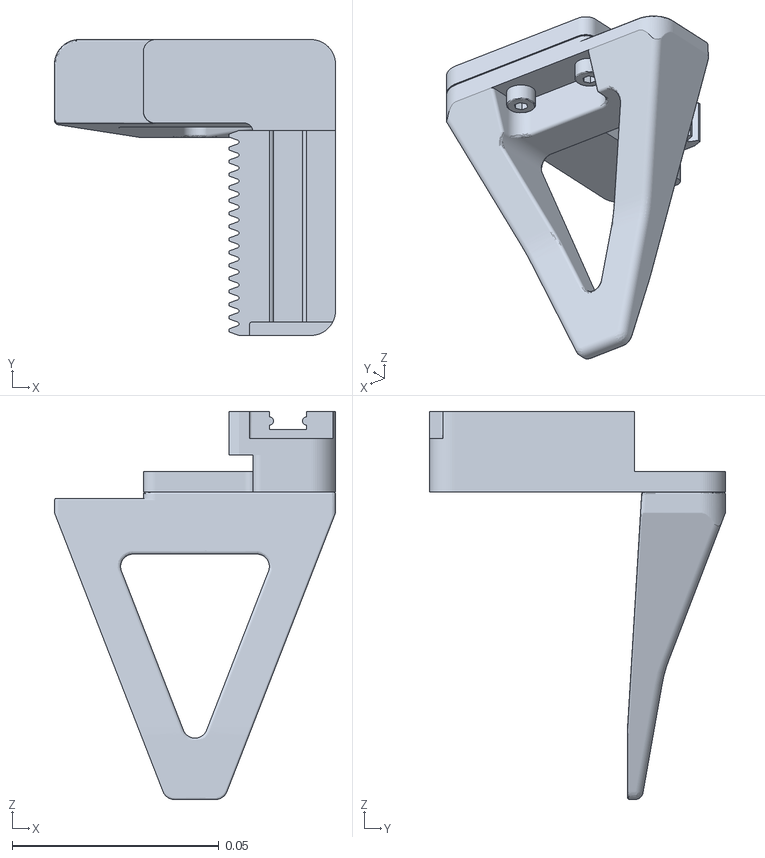
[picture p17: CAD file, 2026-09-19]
hardware/reference/i2rt_linear_4310/tip_right.stl
0.068 x 0.0716 x 0.0938

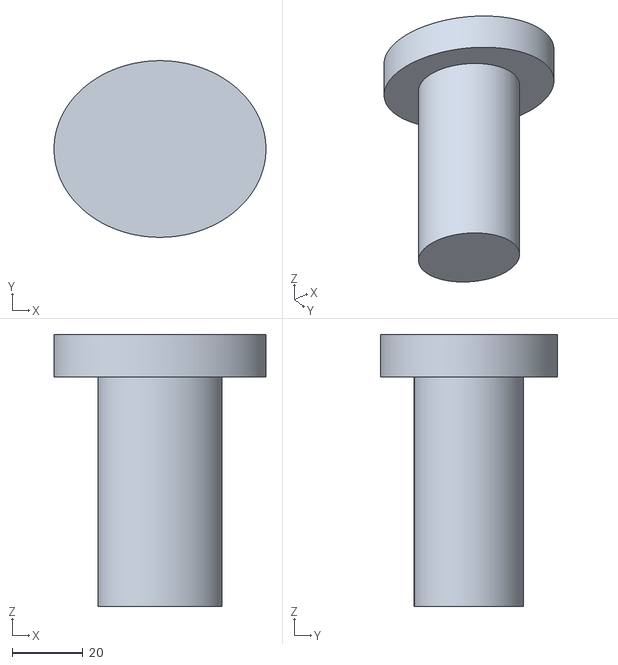
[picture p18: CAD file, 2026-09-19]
pos-tracking/quest_mount/controller_ENVELOPE_NOT_FOR_FIT.stl
60.0 x 50.0 x 77.0

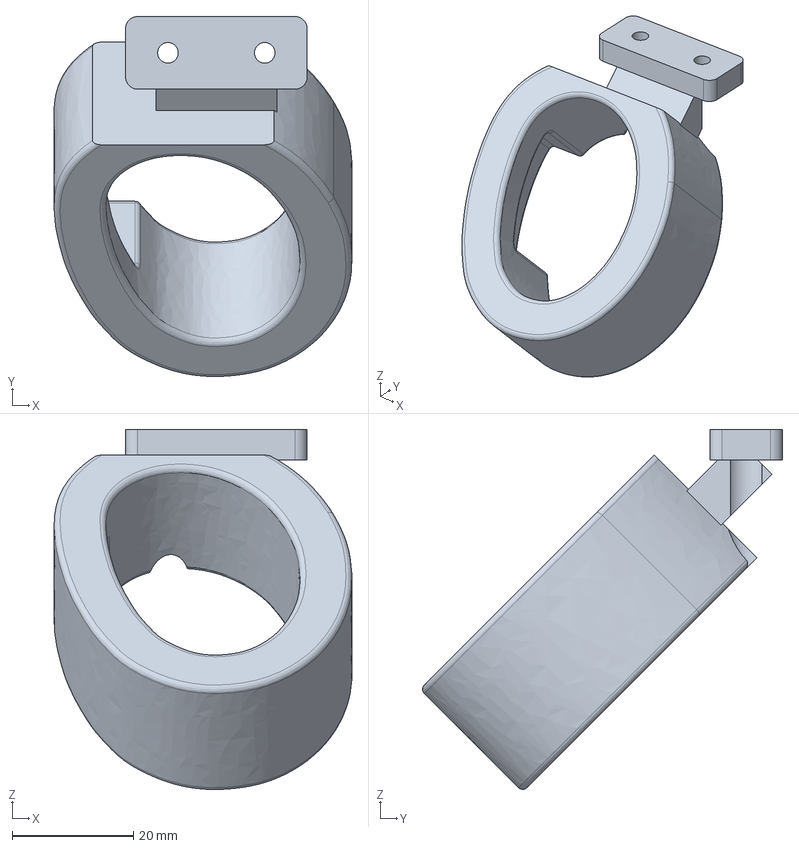
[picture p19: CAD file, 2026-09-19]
pos-tracking/quest_mount/handumi_v1/handumi_yam_left_support.step
49.2 x 59.5 x 59.5 mm

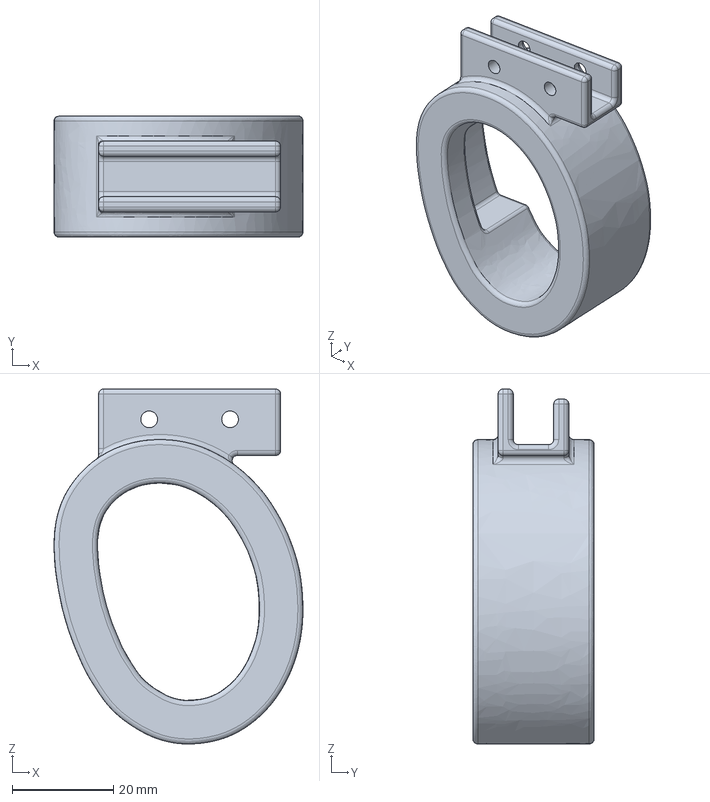
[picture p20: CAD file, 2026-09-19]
pos-tracking/quest_mount/handumi_v1/source/left_controller_support.step
49.2 x 24.0 x 70.2 mm

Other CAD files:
hardware/realsense_d405/d405_mount_print.step
bambu/full_rebuild/tip_right_prototype.stl
hardware/rail_stops/quest_plate_and_stops_A1_PETG.3mf
hardware/realsense_d405/D405_ENVELOPE_NOT_FOR_PRINT.step
hardware/rail_stops/plate_v6_quest_and_rail_stops.stl
hardware/rail_stops/plate_v6_with_rail_stops.step
hardware/rail_stops/plate_v6_with_rail_stops.stl
hardware/rail_stops/rail_stop_A_print_2.stl
hardware/rail_stops/rail_stop_B_print_2.step
hardware/rail_stops/rail_stop_B_print_2.stl
hardware/rail_stops/rail_stops_four_flat.3mf
hardware/rail_stops/rail_stops_four_on_plate.stl
hardware/realsense_d405/d405_mount_assembly.stl
hardware/realsense_d405/d405_mount_print.stl
hardware/realsense_d405/d405_rear_fit_gauge.step
hardware/realsense_d405/d405_rear_fit_gauge.stl
pos-tracking/quest_mount/handumi_v1/handumi_yam_left_support.stl
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

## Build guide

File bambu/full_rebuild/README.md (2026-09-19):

# Complete tinyumi rebuild

Open `tinyumi_full_rebuild_A1_PETG.3mf` in Bambu Studio. Two plates for one gripper;
Quest controller support excluded; print one separately if needed.

Plate 1: one combined Quest/rail-stop base, two jaw adapters with integral racks,
two L-brackets, two curved finger holders, one camera mount, four pinion fit
variants (install only one), and four rail stops (two A/two B).
Plate 2: one left and one right rigid fingertip prototype.

A1, 0.4 mm nozzle, Generic PETG, 0.2 mm layers, four walls, five top and bottom
layers, 30% gyroid infill, normal snug supports, three interface layers.
All objects start on Z=0 and have separated footprints. See manifest.json.
These are starting print settings, not mechanically validated settings.

## Inserts and assembly

Existing part holes have been retained; no supplier-specific resizing applied.
Check actual insert outside diameter AND length before printing the body.
The original build calls for M3-thread, nominal 4 mm OD, 5 mm-long inserts.
The 4.4 mm OD OnlyScrews option is not confirmed compatible with these holes.
Do not compensate every hole globally: that also changes bearing and screw fits.

Install inserts while each part is separate. Let them cool before fitting screws.
Check screw engagement and available hole depth before tightening; bottoming a
long screw can damage the insert pocket without clamping the joint.
Base rail-stop screws are M3x8 countersunk; the Quest support uses M3x10
countersunk. See [the fastener table](../../docs/fasteners.md) for other CAD starting sizes
and the unverified M4 × 12 fingertip trial suggestion.
Trial-fit the pinion variants and keep the smoothest one. Confirm free jaw
travel and stop contact before installing the controller.

## Prototype fingertip provenance and limits

The tips derive from the local I2RT Linear 4310 reference STLs, scaled from metres
to millimetres. A solid plane cut at original Z=-145.61 mm removes the merged
stock rack above the tip mounting face. Original tip geometry, including mounting
pockets, is retained. Unlike the earlier illustration cuts, these use manifold
solid trimming and export watertight positive-volume meshes.

This validates mesh closure only. Mounting fit, material grip, strength, insert
fit, and equivalence to purchased tips have not been physically validated.
The rigid PETG prototypes do not establish the compliance/friction of stock tips.
Check these on the bracket before treating them as finished replacements.
Source and MIT license: ../../hardware/reference/i2rt_linear_4310/source.json
and ../../hardware/reference/i2rt_linear_4310/LICENSE.

Regenerate the unsliced project with:
`uv run --with trimesh --with numpy --with manifold3d python bambu/full_rebuild/build.py`
Save from Bambu Studio after slicing to retain its native project metadata.

## D405 camera version

`tinyumi_full_rebuild_D405_A1_PETG.3mf` substitutes the one-piece RealSense D405
bracket for the fisheye camera mount. Other quantities are identical.
See ../../hardware/realsense_d405/README.md for camera screw limits and fitting.
Regenerate with `build.py --d405` using the same uv packages above.

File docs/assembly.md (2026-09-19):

# tinyumi assembly

This guide follows the CAD assembly. The new mounts, stops and printed tips
still need physical fit verification. Use the [fastener table](fasteners.md)
for screw sizes, quantities and confidence; it supersedes the original blanket
advice to pick unspecified screws from an assortment.

## 1. Choose and print parts

Use one of the [two-plate projects](../bambu/full_rebuild/README.md), selecting
D405 or original fisheye camera. These contain the combined Quest/rail-stop base,
two adapters with integral racks, two L-brackets, two finger holders, four
pinion fit variants, four stops and two prototype tips. Install only one pinion.
The [Quest support](../pos-tracking/quest_mount/handumi_v1/README.md) is separate:
print the appropriate left or right support if needed. Original YAM Linear 4310
tips may replace the rigid prototypes.

## 2. Install inserts

Install M3 inserts in the locations listed in the [insert table](fasteners.md#heat-set-insert-locations)
while parts are separate. Keep them square and allow them to cool.
The axle insert belongs in the **base**, not in the pinion’s bearing recess.
The larger tip and holder holes are clearance holes, not M3 insert pockets.

## 3. Rails and end stops

Mount two 100 mm MGN9 rails with one MGN9C carriage each. Align them so each
carriage travels freely. Keep carriages restrained until stops are installed.
Use the [four printed stops](../hardware/rail_stops/README.md), two A and two B
on matching diagonals, with M3 × 8 countersunk screws in the combined base’s
side-facing inserts. The original unmodified base cannot accept these stops.
Gently verify that each carriage contacts its stop before leaving the rail;
clone carriage dimensions may differ. If retaining original rubber caps instead,
trim only enough to clear the adapters while still retaining the carriages.

## 4. Adapters and pinion

Bolt one adapter to each carriage, with both integral racks facing the central
pinion. Stack two MR63ZZ bearings (3 × 6 × 2.5 mm each) in the pinion. Mount the
axle through the bearings into the base insert. Check the complete head/bearing
stack: the screw must retain the axle without clamping the rotating gear.

Trial-fit the four pinion variants and use the smoothest one. Moving either jaw
should move the other symmetrically without binding, tooth skipping or excessive
wobble. Verify axle retention as well as free rotation.

## 5. L-brackets, finger holders and tips

Attach each L-bracket to its adapter using the two outer mounting positions.
Attach each curved finger holder at its smaller centre mounting hole. Trial-fit
the tips and holder together before final tightening: one lower joint is shared.
There are two tip screws per side. **M4 × 12 is only a suggested trial size**;
confirm the receiving thread and both clamped stacks as explained in the
[fingertip guidance](fasteners.md#fingertip-joint-measure-before-tightening).

Thread one hook-and-loop strap through each holder, two straps per gripper.
Check hand clearance through the entire jaw stroke.

## 6. Camera

For D405, follow the [mount guide](../hardware/realsense_d405/README.md): two
M3 × 8 socket-head screws through the rear pad, and two M3 × 8 countersunk screws
into the base. Camera screw entry must not exceed 4 mm. Test the supplied fit
gauge first. Check the actual cable plug and bend clearance.

For the original fisheye, use its camera mount on the base’s camera-side
underside interface. The jaw L-brackets belong on the adapters, not at this
camera joint. Set and lock the lens focus before calibrating intrinsics.

The D405 mount has a new pose. Calibrate the selected camera and its transform
to the gripper; do not reuse fisheye calibration for D405.

## 7. Markers and pose source

Print [tip markers](../pos-tracking/markers/tip_markers_9mm_ID13_14.pdf) at 100%
scale, one 9 mm marker per tip. Seat them flat with full-face tape and verify
visibility across the aperture. The original fisheye placement was 25 mm from
the gripper base; check visibility again with D405.

If using Quest, attach the support with two M3 × 10 countersunk screws in the
revised underside pad. Verify real controller fit, retention, tracking surfaces,
buttons and hand clearance. Calibrate controller-to-tool pose and synchronize
pose with camera data; this repository does not supply a completed Quest capture
pipeline. The [marker-ball tracker](../pos-tracking/README.md) remains an
alternative with its own assembly and calibration procedure.

## 8. Final fit check

Confirm inserts do not rotate, joints clamp before screws bottom, rails remain
parallel, stops retain both carriages, and the axle is retained while the pinion
spins freely. Sweep the jaws with straps, camera cable and optional controller
in place. Check fingertip fastening, marker visibility and camera view before
using the gripper to collect data. Record measured screw lengths and any fit
changes for the next revision.

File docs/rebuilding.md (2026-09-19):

# Rebuilding tinyumi assets

Run from the repository root with Python 3.12 and `uv`. The checked-in CAD and
print projects can be used without running the generators. Dependencies below
are not locked; generated files may vary with tool versions.

```sh
uv run --python 3.12 --with cadquery --with trimesh --with matplotlib python pos-tracking/quest_mount/handumi_v1/build.py
uv run --python 3.12 --with cadquery --with trimesh --with matplotlib python hardware/rail_stops/build.py
uv run --python 3.12 --with cadquery --with trimesh --with matplotlib python hardware/realsense_d405/build.py
uv run --python 3.12 --with trimesh --with numpy --with manifold3d python bambu/full_rebuild/build.py
uv run --python 3.12 --with trimesh --with numpy --with manifold3d python bambu/full_rebuild/build.py --d405
```

The support generator uses the checked-in `output/models/` assembly illustration
for conservative clearance checks. Its simplified rails, camera and tip hardware
are documented in the adjacent source manifest; it is not supplier assembly CAD.
The full-project generator uses the checked-in rail-stop 3MF for printer settings.
Open the resulting projects in Bambu Studio, inspect supports and slice before
printing. Regeneration produces unsliced projects.

Generators assert mesh/CAD properties and write local manifests or validation
reports. These checks establish geometry, not physical fit, print strength,
tracking accuracy or real screw engagement. Source licenses and provenance are
in each relevant `source/` or `hardware/reference/` folder.

Legacy upstream part names and illustration paths remain stable to preserve
CAD references. Newly packaged full projects use the `tinyumi_full_rebuild` name.

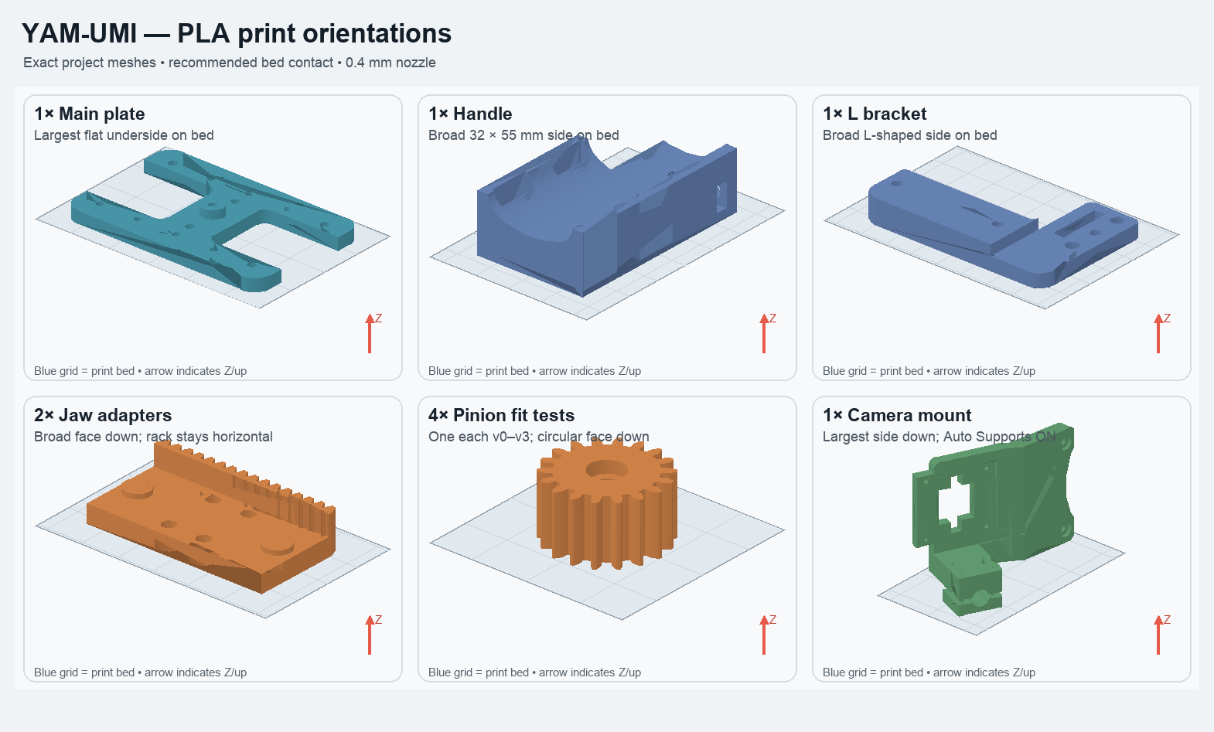
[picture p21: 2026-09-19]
renders/yam_umi_main_print_orientations.png

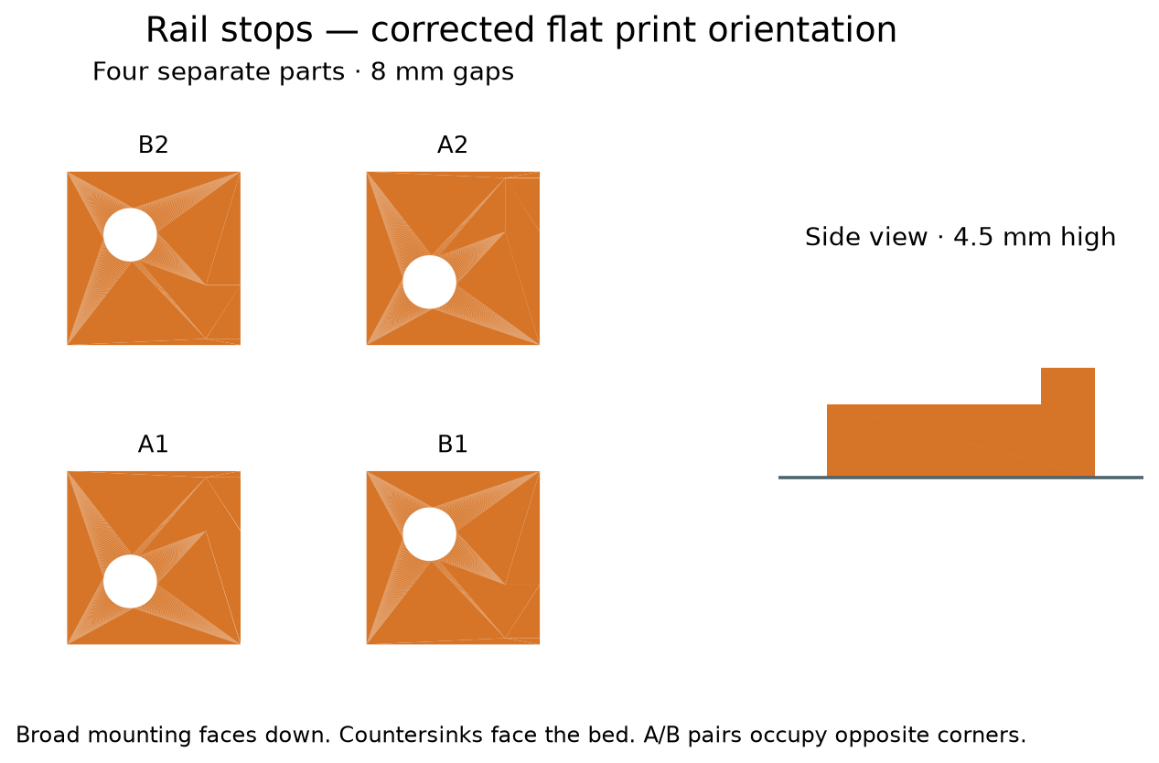
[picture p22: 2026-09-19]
hardware/rail_stops/rail_stops_print_layout.png

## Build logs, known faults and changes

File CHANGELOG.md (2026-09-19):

# tinyumi changes

## 2026-09-19 — initial tinyumi fork

Started from Yosub Shin’s YAM-UMI at `2862fe2`; merged upstream through
`9d202bc` before publication. Original history and MIT notice retained.

- Incorporated newer upstream camera/shutter guidance and dynamic tracking
  documentation, preserved in `DESIGN.md` and `pos-tracking/`.
- Adopted the **tinyumi** name and rewrote the entrypoint around the current
  build. Preserved original rationale and reported measurements in `DESIGN.md`.
- Added HandUMI-derived left/right controller supports with shortened angled
  mounting tabs, a revised base pad, pinned source CAD and Apache-2.0 license.
- Added four printed rail end stops, A/B print layouts, and a combined base
  accepting both the stops and Quest support.
- Added a one-piece D405 mount, rear-hole fit gauge, schematic camera envelope,
  assembly preview and geometric validation report.
- Added rigid left/right fingertip prototypes trimmed from pinned I2RT meshes,
  with source hashes and MIT attribution. Grip and mounting fit remain untested.
- Packaged fisheye and D405 Bambu A1 PETG projects, two plates each, with
  generators and object manifests. Quest supports are printed separately.
- Documented screw quantities, insert locations and assembly order. Corrected
  the pinion insert location and jaw-bracket placement. M4 × 12 tip screws are
  explicitly an unverified trial suggestion, not a confirmed hardware spec.
- Included assembly illustrations and geometric checks; excluded scratch work
  and superseded generated PDF guides from publication.

The original mechanism and tracking documentation remain available. New hardware
has not been physically validated; no Quest capture integration or D405 calibration
is claimed. Original settled-hold tracking measurements apply only to the
upstream marker-based setup.
